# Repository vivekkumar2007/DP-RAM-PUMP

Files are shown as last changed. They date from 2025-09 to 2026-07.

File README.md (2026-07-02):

# 💧 Low-Cost DIY Hydraulic Ram Pump — CAD Model

> A zero-electricity, water-powered pump designed for sustainable water lifting in mountainous regions.  
> A project of the **Design Practicum course at IIT Mandi**

---

## 📌 Overview

People living in mountainous regions often rely on rivers at lower altitudes for their water supply — making it a daily challenge to carry water uphill. Electrical pumps are costly to install and run. This project presents a **Hydraulic Ram Pump** — a fully mechanical, self-operating pump that uses only the kinetic energy of flowing water to lift a portion of it to a much greater height, with **zero operating cost**.

This repository contains the **SolidWorks CAD model** of the prototype built and tested at IIT Mandi.

---

## ⚙️ How It Works

A Ram Pump exploits the **water hammer effect**:

1. Water flows down the drive pipe, gaining kinetic energy from the supply head.
2. The **waste valve** (open by default due to its own weight) allows water to flow out until the rush of water forces it shut.
3. The sudden valve closure creates a **pressure spike** (water hammer) that travels through the pump body.
4. This spike opens the **check valve** and pushes water into the **air chamber**, where compressed air smoothens the pulsation and forces water steadily up the delivery pipe.
5. Once the pressure drops, the waste valve opens again — and the cycle repeats automatically.

```
Water Source → Drive Pipe → Waste Valve → Check Valve → Air Chamber → Delivery Pipe → Storage
```

---

## 📐 Design Specifications

| Parameter | Value |
|---|---|
| Supply / Drive Head (Hs) | 1.4 m |
| Max Lift Height | 10 m (flow diminishes at max lift) |
| Measured Lift (tested) | ~6 m |
| Drive Pipe | 32 mm (1¼ inch) CPVC SDR11, 25 ft |
| Delivery Pipe | 19 mm (¾ inch) CPVC |
| Pressure Chamber | 110 mm cap, 42 cm length |
| Waste Valve | 1 inch brass waste valve |
| Check Valve | 1.25 inch brass spring check valve |
| Inlet Flow Rate (both pumps) | 0.2 L/s |
| Delivery Flow Rate | 0.0238 L/s |
| Pump Efficiency | ~51% (improvable with larger delivery pipe) |
| Configuration | 2 Ram Pumps in Parallel |
| Material | CPVC pipes, brass valves, steel mesh |
| Prototype Cost | ₹22,000 |

---

## 🧮 Key Equations

**Input Power:**
```
P_in = ρ × g × Q_in × H_s
```

**Head Loss (Darcy-Weisbach):**
```
H_f = f × (L/D) × (V² / 2g)
```

**Water Hammer Pressure (Joukowsky):**
```
ΔP = ρ × c × ΔV
```
Where `c` ≈ 1200 m/s (wave speed in CPVC), giving a hammer pressure of ~2.64 × 10⁶ Pa — far exceeding the delivery pressure of 58,800 Pa needed to lift water 6 m.

**Efficiency:**
```
η = P_out / P_in = (ρ × g × Q_out × H_d) / (ρ × g × Q_in × H_s)
```
Current prototype efficiency: **~51%** (can be improved by increasing delivery pipe diameter to 1 inch)

---

## 🧩 Components List

| Component | Specification |
|---|---|
| Drive Pipe | CPVC SDR11, 32 mm, 25 ft (×2 for parallel pumps) |
| Pressure Chamber | 110 mm CPVC pipe, 42 cm length + 4-inch cap |
| Waste Valve | 1 inch brass waste valve |
| Check Valve (Spring) | 1.25 inch brass spring check valve |
| Delivery Pipe | CPVC, ¾ inch (1 inch recommended for less friction) |
| Inlet Filter | Steel wire mesh on storage tank |
| Storage Tank | With 2 bottom outlets for parallel pump setup |
| Fittings | T-connectors, elbows, union fittings, reducers, tank nipples |
| Sensors (optional) | DN32 Water Flow Sensor, Pressure Transducer |
| Microcontroller (optional) | ESP32 for monitoring |

---

## 🧾 Bill of Materials

| Part | Price (INR) |
|---|---|
| CPVC Ball Valve 1.25 inch / 32 mm | ₹423.74 |
| CPVC No Return Valve 1 inch | ₹480 |
| CPVC Tank Nipple 32 mm | ₹160 |
| CPVC FTA 32 mm | ₹370 |
| CPVC Pipe 32 mm SDR11 (per 3 m) | ₹700 |
| Reducer 1.25 inch – 1 inch | ₹370 |
| Union Fittings 32 mm | ₹160 |
| G.I Nipple 32 mm | ₹20 |
| CPVC Elbow 32 mm | ₹70 |
| CPVC Tee 32 mm | ₹90 |
| Wire Mesh | ₹22/sq |
| CPVC MTA 32 mm | ₹470.01 |
| CPVC Reducer Bush | ₹186 |
| ESP32 (optional) | ₹651 |
| DN32 Water Flow Sensor (optional) | ₹1,299 |
| Pressure Transducer (optional) | ₹922.50 |
| 4-Channel 5V Relay Module (optional) | ₹599 |
| Step-Down Converter 6V–40V to 5V (optional) | ₹299 |

---

## 🗂️ Repository Structure

```
DP-RAM-PUMP/
├── ram pump final/       ← All SolidWorks part & assembly files
│   ├── final assembly.SLDASM
|   ├── final assembly.step
│   ├── bb pipe.SLDPRT
│   └── ...
├── render/               ← Rendered images of the CAD model
├── galvanized.jpg
└── README.md
```

> 📝 Open the `final assembly.SLDASM` assembly file from the `ram pump final/` folder in SolidWorks — keep all files in the same folder so part references resolve correctly.

---

## 🖥️ Software Used

- **CAD Software:** SolidWorks 2021
- **Neutral formats available:** STEP / STL (add if exported)
- All part and assembly files are in a single folder — keep them together so SolidWorks can resolve all references.

---

## 🔧 Build Instructions (Summary)

1. Cut two 25 ft lengths of 32 mm CPVC SDR11 pipe — these are the drive pipes for the two parallel pumps.
2. Prepare a storage tank with two outlets at the bottom and cover the opening with steel mesh for filtration.
3. Install a ball valve on each drive pipe to open/close the pumps independently.
4. At the far end of each drive pipe, connect the **1 inch brass waste valve** using a T-connector.
5. Connect the **1.25 inch brass spring check valve** after the waste valve — this allows flow only into the air chamber.
6. Build the **pressure chamber**: cut a 4-inch CPVC pipe to 42 cm, cap one end, and attach a reducer bush and threaded socket at the other end.
7. Connect both pump outputs via T-connectors into a single delivery channel. Run the delivery pipe to the desired height.
8. For river installation: drill holes in the intake pipe, wrap with mesh, and submerge in the river.

---

## ▶️ Operation Instructions

1. Fill the storage tank (or place the mesh-covered inlet pipe in a flowing river).
2. Open the ball valves on both drive pipes.
3. Once the waste valves cycle shut for the first time, the pump should start self-cycling. If not, manually open and close the waste valve a few times to purge trapped air.
4. Check all joints for leaks. Ensure the drive pipes have no bends.
5. Open the delivery pipe ball valve — water will reach the outlet height within a short time and develop a steady flow.
6. Periodically clean the valves and pipes to prevent sediment build-up.

**Troubleshooting:** If the waste valve is not cycling, ensure the delivery pipe outlet is above the pump height to build sufficient back pressure.

---

## 📊 Performance Comparison

| Parameter | Ram Pump | Electrical Motor |
|---|---|---|
| Initial Cost | ₹4,000 – ₹12,000 | ₹18,000 – ₹60,000 |
| Operating Cost | ₹0 | ₹500 – ₹3,000/month |
| Power Requirement | None (gravity-fed, min. 0.7–2 m head) | Electricity required |
| Maintenance Cost | ₹0 – ₹500 (valve cleaning) | ₹1,000 – ₹6,000 |
| Installation Time | Hours | 1–2 days |
| Skill Required | Very low | Electrician + pump technician |
| Water Wastage | Very low (waste returns to natural stream) | None |

---

## 📚 References

- [Comprehensive Guide to RAM Pumps — Valves Online](https://www.valvesonline.com.au/blog/comprehensive-guide-to-ram-pumps/)
- [Optimizing Hydraulic Ram Pump Performance — Indian Journal of Science & Technology](https://indjst.org/articles/optimizing-hydraulic-ram-pump-performance-experimental-insights-on-waste-valve-height-and-uncertainty-analysis)
- [Effect of Waste Valve Tuning on Hydraulic Ram Pump Efficiency — SciTePress](https://www.scitepress.org/publishedPapers/2021/109430/pdf/index.html)
- [DIY Hydraulic Ram Pump — Instructables](https://www.instructables.com/Hydraulic-Ram-Pump/)
- [Efficiency of a Working Hydraulic Ram Pump System — ISROSET](https://www.isroset.org/pub_paper/WAJES/7-ISROSET-WAJES-04993.pdf)

---

*A Design Practicum project at IIT Mandi — because water should flow uphill too. 💧*

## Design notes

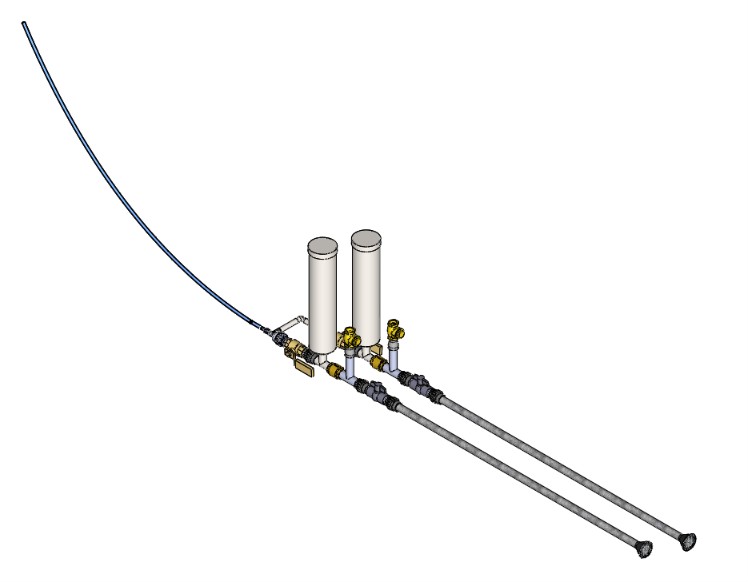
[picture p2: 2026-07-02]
render/Isometric_view.jpg

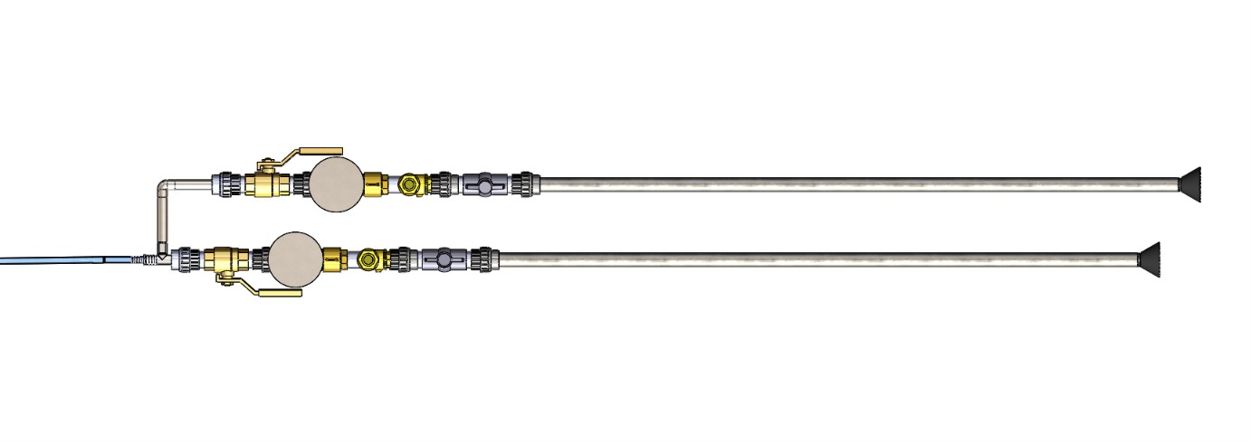
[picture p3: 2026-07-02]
render/Top_view.jpg

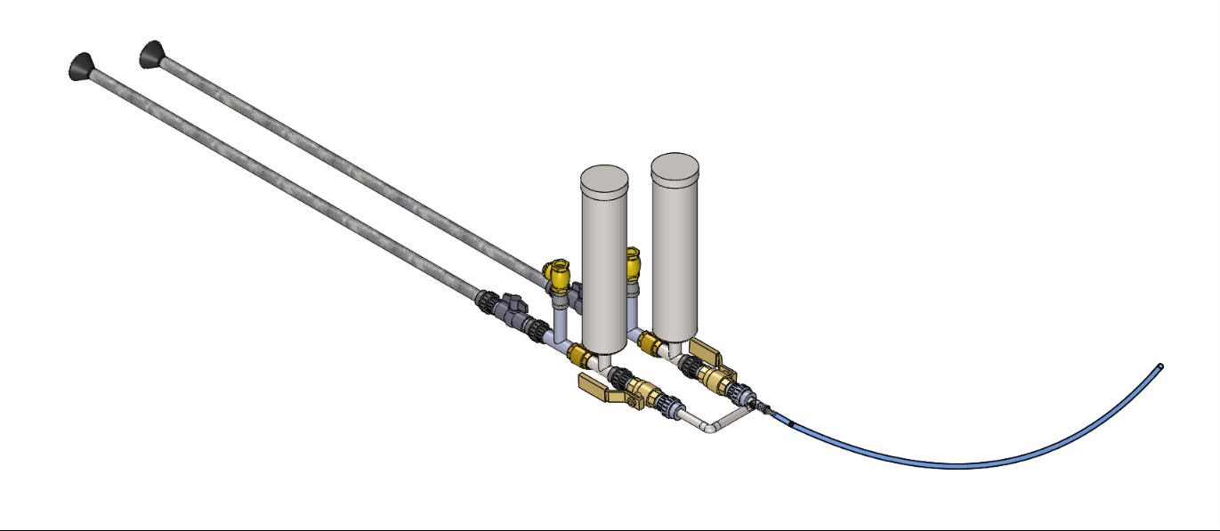
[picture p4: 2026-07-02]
render/other_view.jpg

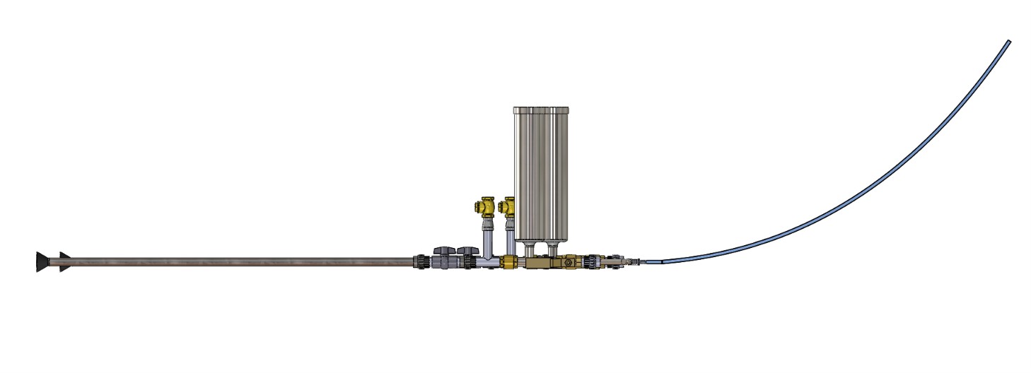
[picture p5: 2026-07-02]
render/Front_view.jpg

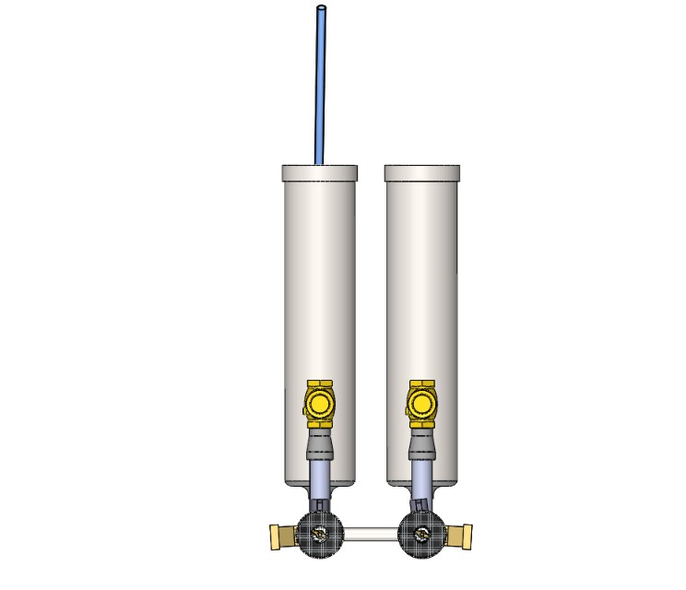
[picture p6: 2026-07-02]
render/Right_view.jpg

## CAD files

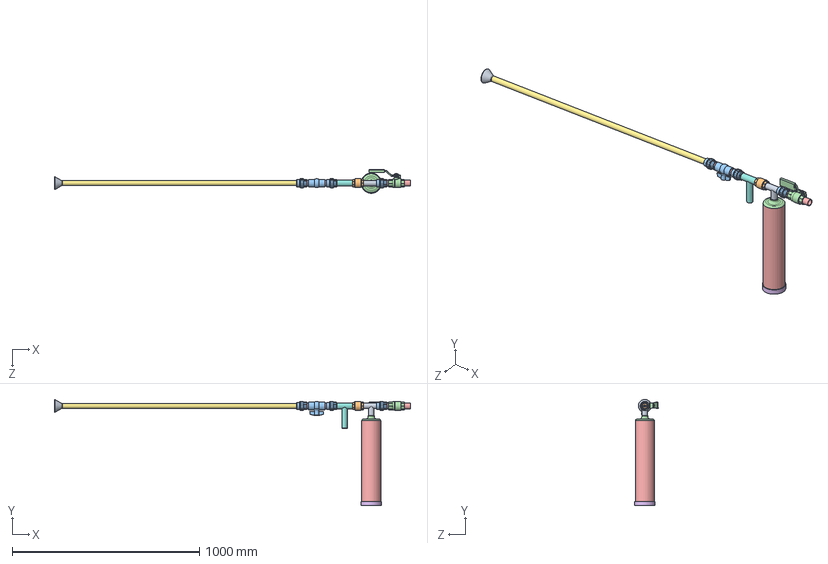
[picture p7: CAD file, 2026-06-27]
ram pump final/Assem1 final.SLDASM
1899.9 x 566.3 x 126.1 mm
e43316
Brass Check Valve York 26-34mm 1in DP ITAP
dd
cc
ee
bb pipe long
waste valve hold
portafilter_funnel
wire mesh filter
Union 32mm x 3
ball_valve_non-venting_dn20__3_4___bsp
connector pipe piece x 4

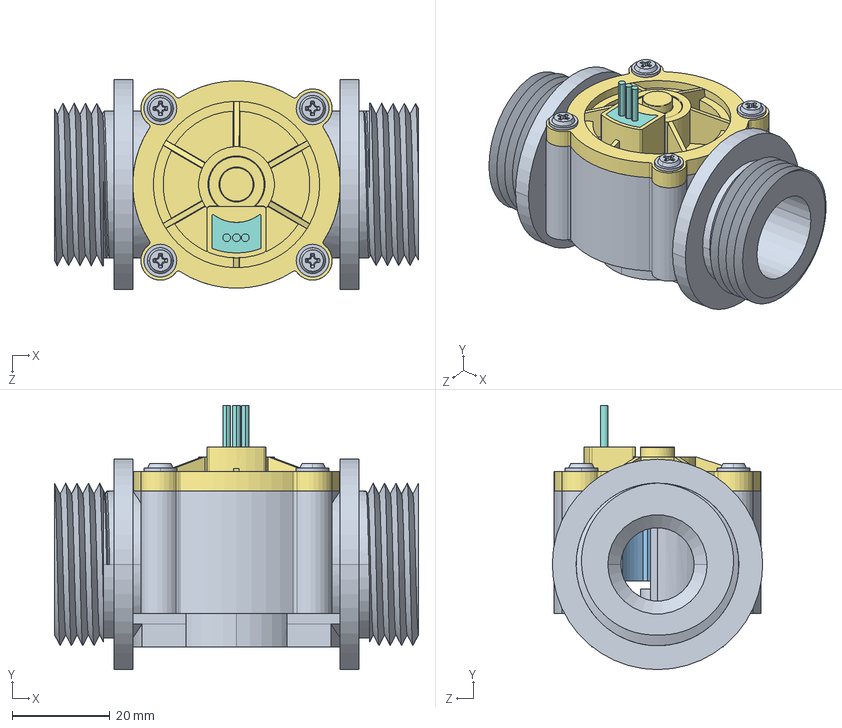
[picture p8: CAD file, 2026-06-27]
ram pump final/FS400A G1, Water Flow Meter.STEP.SLDASM
74.4 x 54.0 x 43.0 mm
Main Body, FS400A G1, Water Flow Meter.STEP
Impeller Shaft, FS400A G1, Water Flow Meter.STEP
Flow Meter Impeller, FS400A G1, Water Flow Meter.STEP
Magnet, Hall Effect Sensor, FS400A G1, Water Flow Meter.STEP
Cover Plate, Flow Meter Impeller, FS400A G1, Water Flow Meter.STEP
Sealing O-Ring, FS400A G1, Water Flow Meter.STEP
Cover Plate, FS400A G1, Water Flow Meter.STEP
Three Wire Connector, FS400A G1, Water Flow Meter.STEP
M3 X 14, SS Pan Head Self Tapping Screw, FS400A G1, Water Flow Meter_DEFAULT.STEP x 4

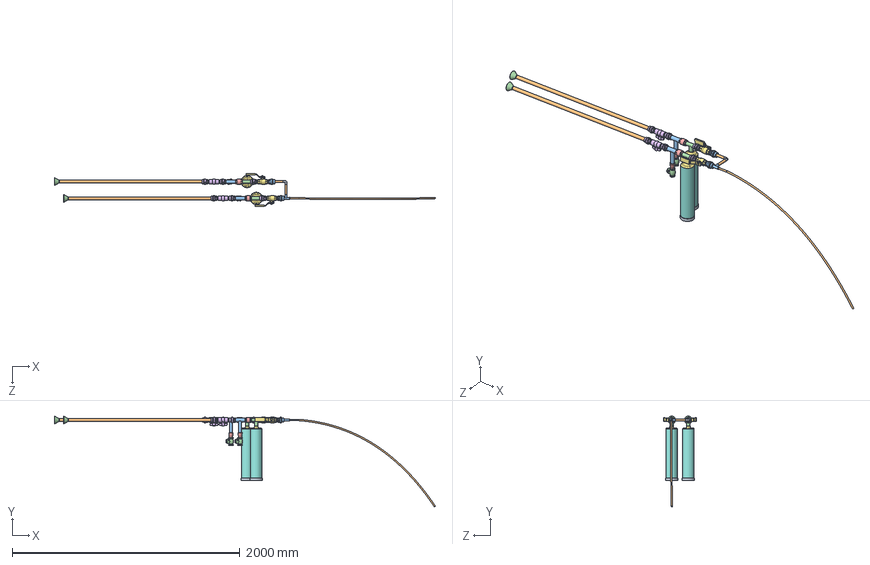
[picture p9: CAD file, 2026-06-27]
ram pump final/final assembly.SLDASM
3342.7 x 797.1 x 291.2 mm
e43316 x 2
Brass Check Valve York 26-34mm 1in DP ITAP x 2
dd x 2
cc x 2
ee x 2
bb pipe long x 2
waste valve hold x 2
portafilter_funnel x 2
wire mesh filter x 2
Union 32mm x 6
ball_valve_non-venting_dn20__3_4___bsp x 2
connector pipe piece x 8
90 Elbow inside threads
bb pipe x 2
smaller e43316 - Copy
Union 1.25 to 0.75 inch x 2
outlet pipe tube1
Brass swing check valve.STEP_1 x 2
inner stopper of waste valve custom nv x 2
connector 0.75 to 0.5 inch

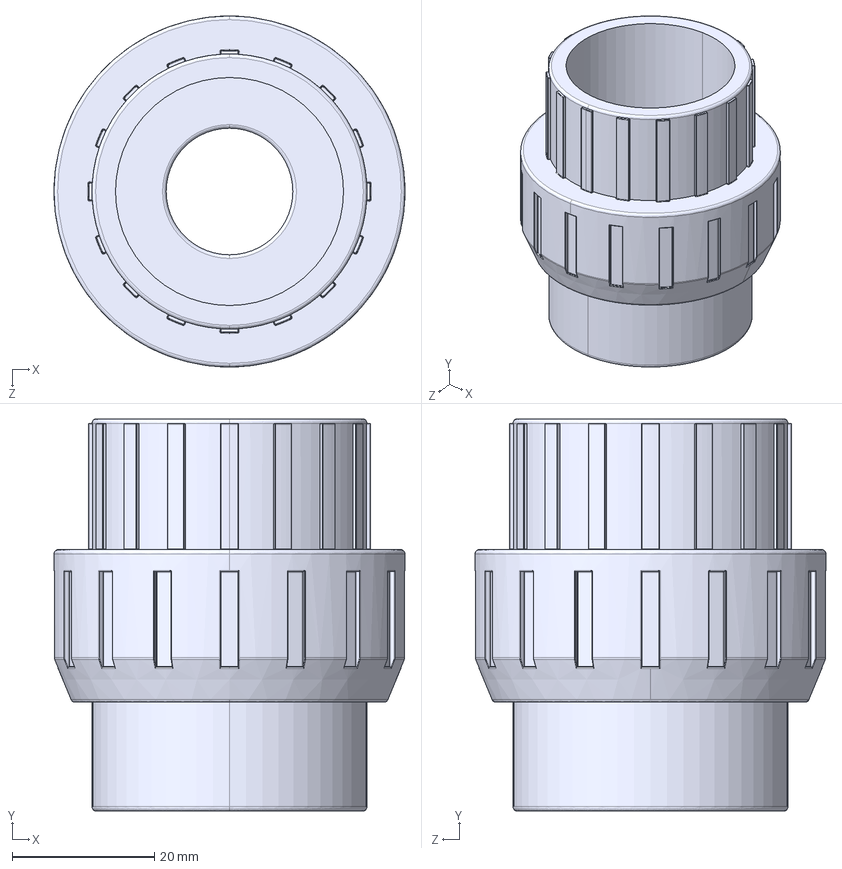
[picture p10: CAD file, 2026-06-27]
ram pump final/Union 1.25 to 0.75 inch.STEP
49.3 x 55.0 x 49.3 mm

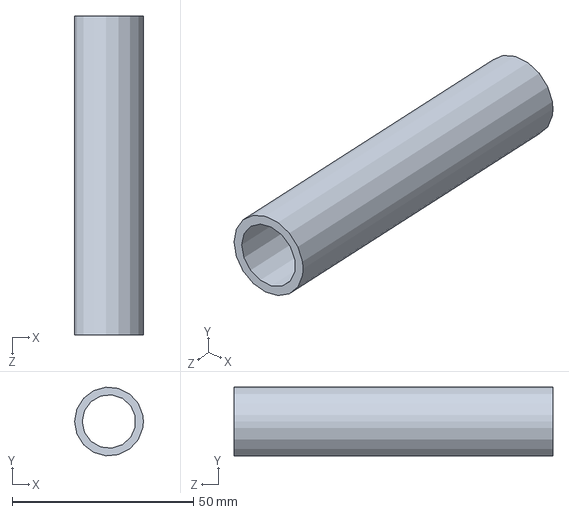
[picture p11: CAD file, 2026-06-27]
ram pump final/bb pipe.SLDPRT
19.0 x 18.9 x 88.1 mm

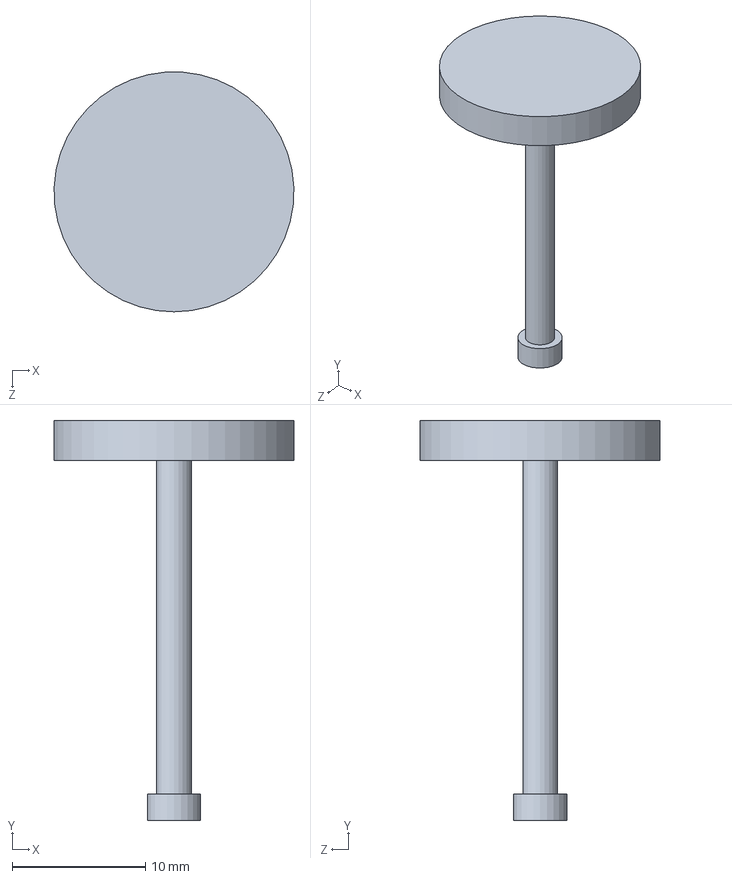
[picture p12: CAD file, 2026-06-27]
ram pump final/inner stopper of waste valve custom nv.SLDPRT
18.0 x 30.0 x 18.0 mm

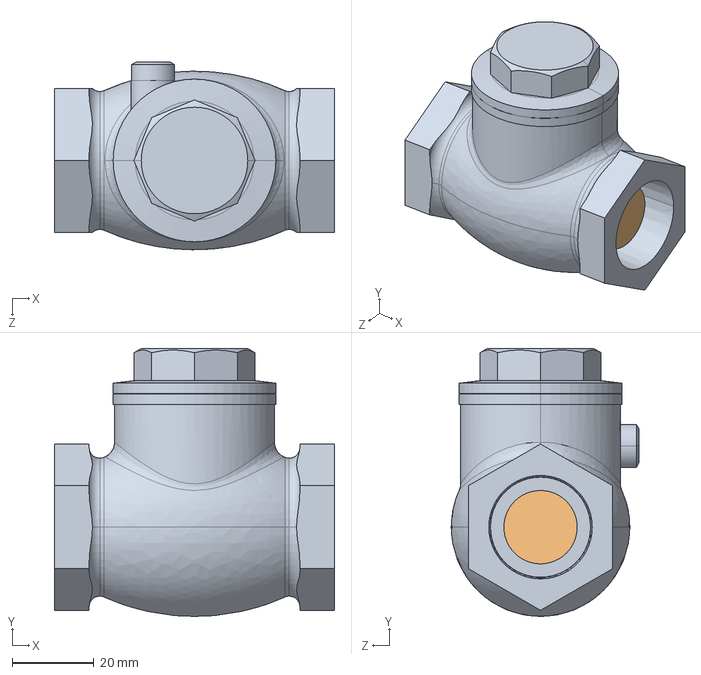
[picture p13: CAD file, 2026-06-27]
ram pump final/waste valve.STEP
68.7 x 65.8 x 46.0 mm
Brass swing check valve.STEP
inner stopper of waste valve custom nv

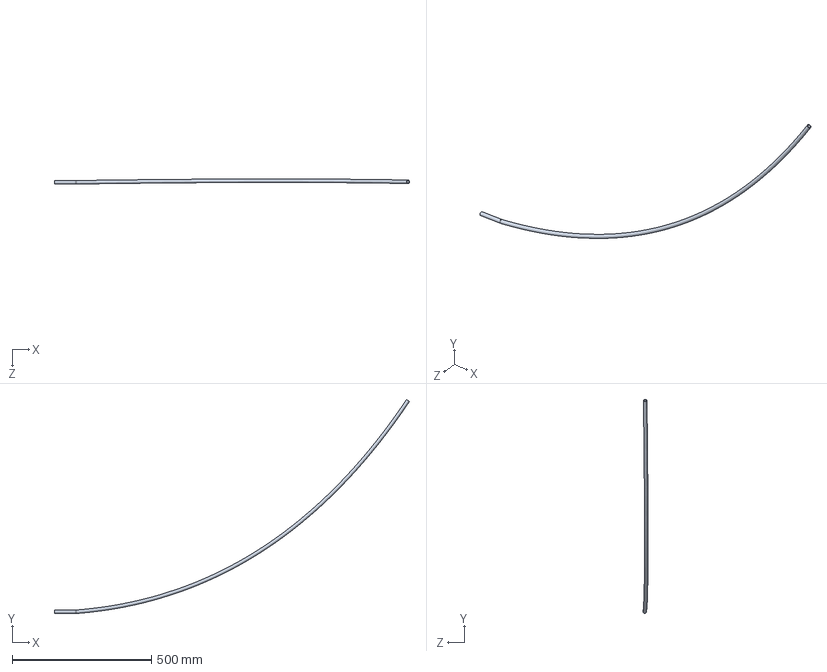
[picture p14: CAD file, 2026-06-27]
ram pump final/outlet pipe tube1.SLDPRT
1275.3 x 768.8 x 18.5 mm

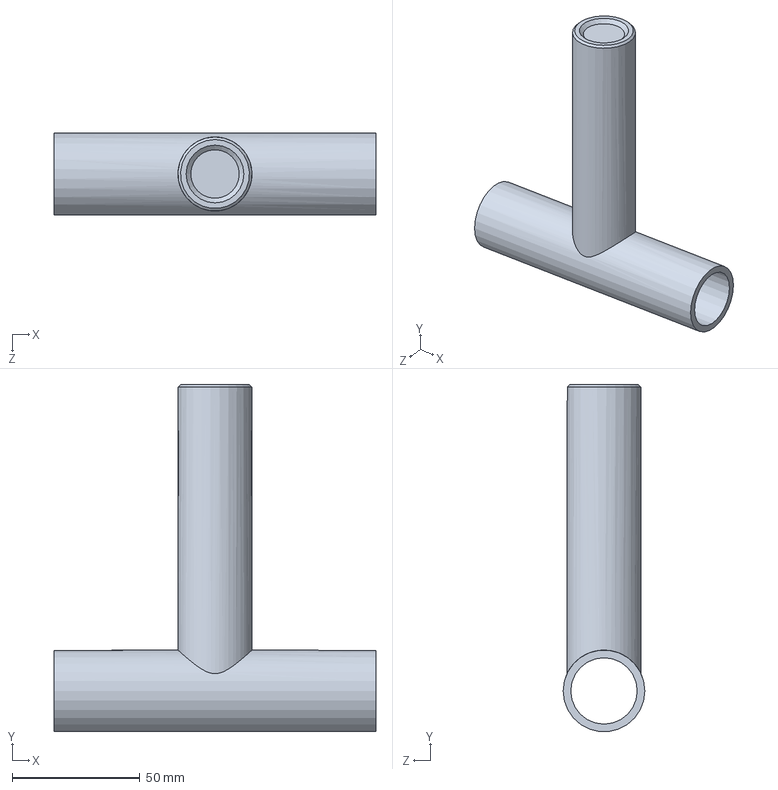
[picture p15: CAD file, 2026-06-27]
ram pump final/waste valve hold.SLDPRT
126.0 x 135.9 x 32.0 mm

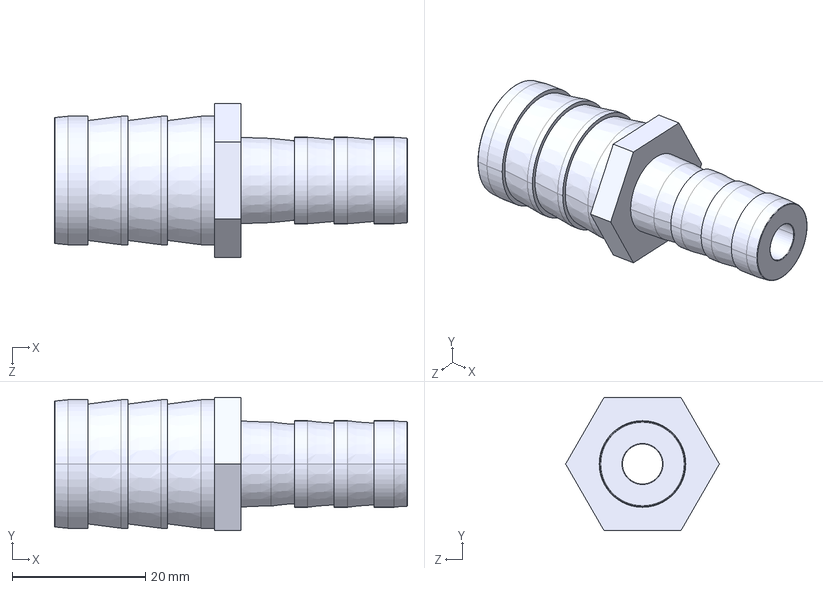
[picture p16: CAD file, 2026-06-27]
ram pump final/connector 0.75 to 0.5 inch.STEP
53.0 x 20.0 x 23.1 mm

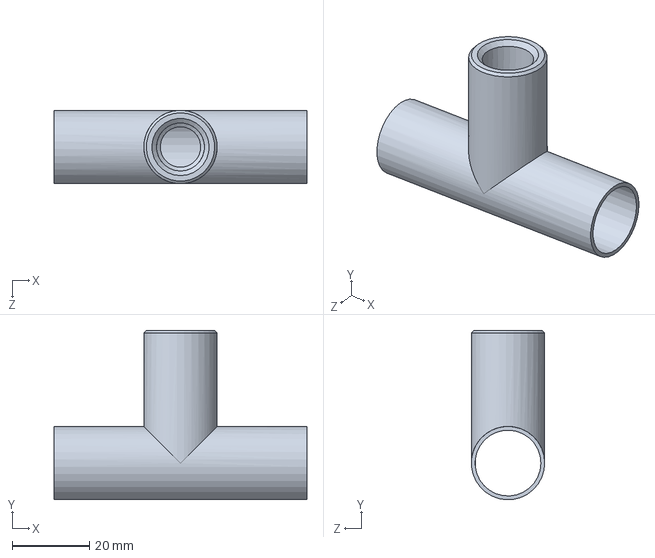
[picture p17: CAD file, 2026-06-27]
ram pump final/smaller e43316 - Copy.SLDPRT
65.7 x 44.0 x 19.0 mm

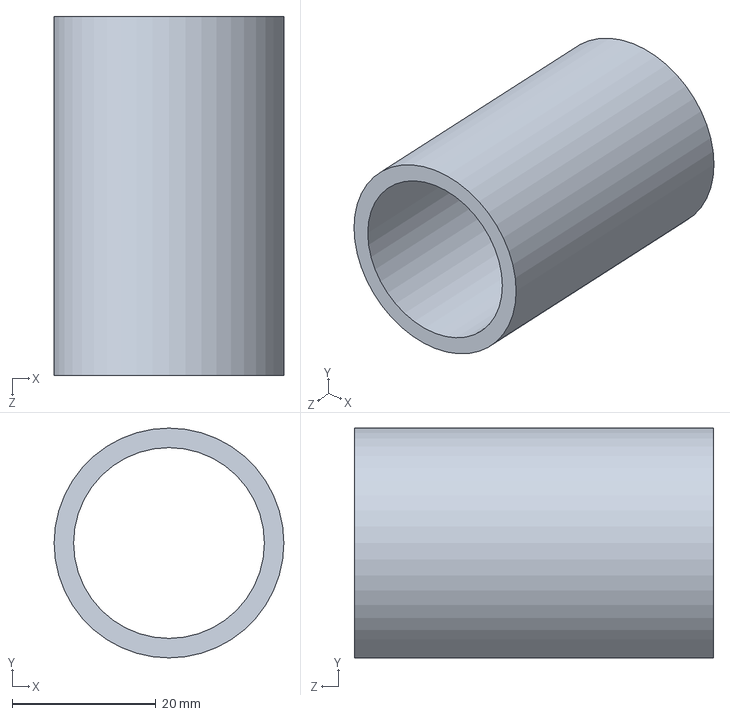
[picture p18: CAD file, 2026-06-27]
ram pump final/connector pipe piece.SLDPRT
32.0 x 32.0 x 50.0 mm

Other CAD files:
ram pump final/Assem2 final.SLDASM
ram pump final/Main Body, FS400A G1, Water Flow Meter.STEP.SLDPRT
ram pump final/Flow Meter Impeller, FS400A G1, Water Flow Meter.STEP.SLDPRT
ram pump final/Three Wire Connector, FS400A G1, Water Flow Meter.STEP.SLDPRT
ram pump final/Sealing O-Ring, FS400A G1, Water Flow Meter.STEP.SLDPRT
ram pump final/Magnet, Hall Effect Sensor, FS400A G1, Water Flow Meter.STEP.SLDPRT
ram pump final/06440763.SLDPRT
ram pump final/1 in union.SLDPRT
ram pump final/359282-3225.SLDPRT
ram pump final/75 MNPT X .5 FNPT BUSHING.step.SLDPRT
ram pump final/8331322_01.SLDPRT
ram pump final/90 Elbow inside threads.SLDPRT
ram pump final/Brass Check Valve York 26-34mm 1in DP ITAP.SLDPRT
ram pump final/Brass swing check valve.STEP.SLDPRT
ram pump final/Brass swing check valve.STEP_1.SLDPRT
ram pump final/Cover Plate, FS400A G1, Water Flow Meter.STEP.SLDPRT
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

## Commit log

2025-09-02 upadated till 2 sep
    [06440763.SLDPRT, 1 in union.SLDPRT, 75 MNPT X .5 FNPT BUSHING.step.SLDPRT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]
2026-06-27 final cad
    [06440763.SLDPRT, 1 in union.SLDPRT, 359282-3225.SLDPRT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]
2026-07-02 added step file of final Assembly
